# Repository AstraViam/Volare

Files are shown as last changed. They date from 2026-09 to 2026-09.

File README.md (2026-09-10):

# Volare

Full electronic, structural and hydrodynamic design code for **Team Volare**,
ICT Mumbai, competing in the **Monaco Energy Boat Challenge 2026**, Energy Class.

A 5 m, 250 kg catamaran. The design objective throughout is **minimum electrical
energy per nautical mile**, not maximum propeller efficiency, and every model
here serves that one number.

> **New here, or picking this up in a new session? Read [`HANDOFF.md`](HANDOFF.md) first.**
> It carries the current state, what is blocked, and what to do next.

---

## What is in here

Four codebases that share one parameter file and are otherwise independent.

### `powertrain/` — battery pack and drivetrain (MATLAB)

The Molicel P50B 26S21P pack, from cell data through busbar sizing and thermal
design to the mission simulation and Monaco compliance check. Numbered folders
`00_common` through `09_hydro` run in dependency order.

```matlab
% open MATLAB at powertrain/
SMOKE_TEST        % fast check
RUN_EVERYTHING    % full run, a few minutes
TEST_ALL          % regression suite
```

### `cad/` — geometry, structure and optimisation (Python)

`cad/scripts/` is pure numpy and scipy: hull geometry, frame sizing, mass
budget, hydrostatics, aerodynamics and the shape optimiser. Every module
self-tests and exits non-zero on failure.

`cad/blender/` consumes `cad/scripts/` to build and render scenes. It never
reimplements the maths.

```bash
python -m venv .venv && .venv/bin/pip install numpy scipy matplotlib
.venv/bin/python cad/scripts/mass.py
blender -b -P cad/blender/build_scene.py
```

### `propulsor/` — contra-rotating propulsor optimiser (MATLAB)

**Currently incomplete.** Core solver files are missing from the repository;
see `propulsor/README.md`.

### `notes/` and `docs/` — the design record

`notes/00` through `notes/09` are the original design discussion and are
**partly superseded**. Where a note and a script disagree, the script wins:
every number in `cad/scripts/` was re-derived or re-measured from the supplied
STLs, and the scripts check themselves.

`docs/design/` holds the current engineering records. `docs/reference/` holds
the Monaco 2026 rules and the cell datasheet.

---

## Layout

```
notes/              00-09 design notes (partly superseded)
docs/design/        current engineering records
docs/reference/     competition rules, datasheets
docs/decisions/     architecture decision records
powertrain/         MATLAB pack + drivetrain project
cad/scripts/        pure numpy/scipy geometry and physics
cad/blender/        bpy scene builders and renderers
cad/freecad/        FreeCAD STEP export
cad/out/            generated .blend, .json, .csv, figures/
propulsor/          contra-rotating optimiser (incomplete)
source_documents/   supplied cockpit STLs — never modify
tools/              repository utilities
```

The two numbered layouts are not cosmetic. `powertrain/TEST_ALL.m` asserts its
exact folder structure, and `P50B_ProjectRoot.m` derives the project root from
its own position inside `00_common/`. The Python modules resolve data through
`Path(__file__).parents[2]`. **Do not flatten either tree.**

---

## Conventions

**Frame.** X forward, Y port, Z up. Origin at centreline × hull mid-length ×
keel bottom. Millimetres everywhere except Blender scenes, which are metres.
Neither supplied STL uses this frame and the two disagree with each other;
`cad/scripts/volare.py` holds both transforms and self-checks them. Always go
through it.

**Supplied parts are locked.** The hulls and beams must not be modified
(ENERGY_REQ_3). `cad/blender/build_scene.py` enforces this.

**Verify by measuring, not by re-reading parameters.** The scene builders
re-measure the geometry they built and fail on disagreement. That has caught
real bugs that parametric checks could not. Add a measured check whenever you
add geometry.

**Report outcomes faithfully.** If a check fails, say so with the number. When a
computed result contradicts a note, say which note and why, and leave a comment
at the site of the correction.

---

## Status

| Subsystem | State |
|---|---|
| `powertrain/` | Structured and consistent. Blocked on two measured cell data files and the shared parameter file. |
| `cad/scripts/` | 14 of 16 modules pass their self-tests. The other two are blocked on the shared parameter file. |
| `cad/blender/` | Requires Blender; not exercised in CI. |
| `propulsor/` | Incomplete. Core solver files missing. |

Full detail, including every missing file and what it blocks, is in
[`HANDOFF.md`](HANDOFF.md).

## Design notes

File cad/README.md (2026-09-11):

# cad/ — geometry, structure and optimisation

The engineering record for everything geometric. Pure Python maths is separated
from Blender scene building on purpose, and that separation is enforced by
review rather than by tooling, so keep it.

| Folder | Runtime | Rule |
|---|---|---|
| `scripts/` | numpy, scipy | No `bpy`, ever. All physics and geometry maths lives here. Every module self-tests and exits non-zero on failure. |
| `blender/` | Blender's Python | Consumes `scripts/`, never reimplements it. Adds `cad/scripts` to `sys.path` itself. Blender has no scipy, so keep heavy imports lazy. |
| `freecad/` | FreeCAD's Python | STEP export only. |
| `out/` | — | Generated `.blend`, `.json`, `.csv`. `out/figures/` holds rendered PNGs. Tracked, so teammates without Blender still have them. |

## Parameters drive the geometry

Every engineering number comes from `powertrain/params/volare_params.json`.
Change it and the change reaches the CAD without anybody editing code. That is
what lets design work and analysis run in parallel.

```
powertrain/params/volare_params.json      the single source of truth
        |
        |  cad/scripts/params.py           stdlib-only loader, works under
        |                                  CPython, Blender and FreeCAD alike
        v
  cad/scripts/volare.py                    shared constants, now derived
        |                                  (mass cap, pilot mass, beam
        |                                   diameter, clamp limits, air)
        +--> parametric.py, frame.py, mass.py, aero.py, ...
        |
  cad/scripts/powertrain.py                computes the layout
        |
        v
  cad/out/powertrain.json                  the one geometry both builders read
        |
        +--> cad/blender/*        meshes, renders, the .blend
        +--> cad/freecad/*        B-rep solids, the STEP a supplier can open
```

Blender and FreeCAD consume the same JSON, so they cannot disagree about where
anything is. Neither reads a parameter directly, which is deliberate: one place
computes the layout, everything downstream consumes it.

The cost of that is staleness, so the FreeCAD build refuses to run when
`cad/out/powertrain.json` is older than the parameter file, rather than writing
a STEP that looks authoritative and describes the previous design. Override
with `VOLARE_ALLOW_STALE=1` only when you mean it.

**What stays hardcoded, on purpose.** The STL-derived numbers in `volare.py`
are measurements of supplied geometry, re-derived from the files and
self-checked at the bottom of that module. They are not design choices anybody
may vary, so they are not parameters.

**Adding a number.** Put it in the parameter file with a provenance tag, then
read it with `params.get("section.name")`. Never add a literal to a script. A
missing parameter raises rather than falling back to a plausible default,
because a CAD model built on invented dimensions looks authoritative and is
not.

## Path contract

Modules resolve the repository root as `Path(__file__).resolve().parents[2]`.
That means **`cad/scripts/` must stay exactly two levels below the repository
root**. Moving it breaks every data path at once. The same applies to
`cad/blender/`.

From that root the modules expect `cad/out/`, `cad/out/figures/` and
`source_documents/`.

## Running

```bash
.venv/bin/python cad/scripts/mass.py
for f in cad/scripts/*.py; do .venv/bin/python "$f" || echo "FAIL $f"; done

blender -b -P cad/blender/build_scene.py -- --out cad/out/volare_baseline.blend
blender -b cad/out/volare_baseline.blend -P cad/blender/render_views.py
```

`powertrain.py` and `pack_fit.py` currently fail on a missing shared parameter
file. See `HANDOFF.md` section 5.

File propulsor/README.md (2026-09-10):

> **STATUS: INCOMPLETE — `main.m` cannot run yet. Being rebuilt, not restarted.**
>
> 13 of the 32 planned files exist. The solver core that is present —
> `bem_rotor.m`, `crp_interaction.m`, `surface_piercing_model.m` and
> `config.m` — is sound and is being kept. What is missing is the surrounding
> layer, starting with `units.m`, whose absence stops `config()` running at all.
>
> **Read [`DESIGN.md`](DESIGN.md) before touching anything here.** It carries
> the architecture, the file-by-file plan, the `params` schema, the staged
> build order, and the MATLAB-versus-Octave decision.
>
> The document below is the engineering rationale to build against.

---

# MEBC Energy Class — Coaxial Contra-Rotating Propulsor Design Tool

MATLAB design and optimisation framework for the contra-rotating propulsor of a
5 m, 250 kg catamaran at 20 knots. Written for Team Volare, ICT Mumbai.

The objective is **minimum electrical energy per nautical mile**, not maximum
propeller efficiency. Everything from hull resistance to battery current is in
one chain, and every unmeasured input is declared, configurable and swept.

---

## 1. Modelling architecture

```
config.m ──► params  (single source of truth for every engineering number)
                │
   resistance_model ──► hull_interaction ──► required thrust T = R/(1-t)
                │
   propeller_geometry ──► hydrofoil_polar ──► bem_rotor ──┐
                                                          ├─► crp_interaction
   surface_piercing_model / submerged_model ──────────────┘   (coupled, iterative)
                │
   gearbox_model ──► motor_model ──► electrical power ──► Wh/nm
                │
   cavitation_model + structural_model + constraints
                │
   objective_function ──► optimization_driver ──► postprocess / export / plots
```

### 1.1 What is actually solved

**Blade element momentum, per rotor** (`bem_rotor.m`). Standard propeller
convention, `U_a = V_a(1+a)`, `U_t = Ωr(1−a′) + V_t`, Prandtl tip *and* hub
losses, 24 cell-centred radial stations. The coupled `(a, a′)` system is reduced
to **one scalar equation per station in the inflow angle φ** and solved by
Illinois (bracketed false position), which converges unconditionally. A
fixed-point iteration on `(a, a′)` was tried first and is unstable at high
solidity; that is why it is not used.

The radial grid is **cell-centred**, deliberately. A station exactly at `r = R`
puts the Prandtl factor at zero, drives the momentum-derived induction to
infinity, forces the solver onto its clamp, and leaves spurious load on an
element that physically carries none.

**Contra-rotating coupling** (`crp_interaction.m`). The rotors are *not* solved
independently:

| Effect | Model |
|---|---|
| Front → rear axial | `g_dn = 1 + Δx/√(Δx²+R_F²)` ≈ 1.25 at 50 mm — the front's induction is only ~25 % developed at the rear disk |
| Rear → front axial | `g_up = 1 − Δx/√(Δx²+R_R²)` ≈ 0.75 — the rear's induction is felt strongly upstream |
| Slipstream contraction | discrete mass conservation, `r₂² = r₂,prev² + u₁(r₁²−r₁,prev²)/u_dn` |
| Swirl transport | `v_θ2 = 2a′₁Ω₁r₁·(r₁/r₂)` — circulation conserved through contraction |
| Swirl recovery | positive `flow.Vt` on the rear rotor, so recovery falls out of the momentum balance — it is **not** an applied efficiency factor |
| Upstream swirl | zero, correctly: an actuator disk induces no tangential velocity ahead of itself |

The coupling is **positive feedback** — more rear loading raises the axial
velocity at the front disk, which unloads the front, which weakens the swirl
feeding the rear. Near lightly loaded operating points the loop gain exceeds
one, the fixed point is *repelling*, and no under-relaxation factor converges.
The coupling is therefore reduced to a single scalar (the interference
amplitude `u`) and solved by secant with a guaranteed-bracket bisection
fallback. This is documented in the file header because it is not obvious and
it will bite anyone who tries to "simplify" it back to a relaxed iteration.

**Speed is not a free variable.** For every candidate design the solver finds
the rotational speed that delivers exactly the required thrust, using a
two-term `T(n) = A n² + B n` model-based secant. The thrust equality constraint
therefore disappears from the optimiser: every evaluated design satisfies it by
construction, or is reported infeasible with a reason.

**Surface piercing** (`surface_piercing_model.m`) is deliberately two-level:

- *Level 1, cycle-averaged*: immersion duty `duty(r) = 1 − acos(h/r)/π`
  multiplies **both** the blade-element force and the annulus momentum area.
  The duty cancels in the induction relations, so partial immersion does not
  change `a` at a given speed — it cuts the thrust, so the solver raises the
  speed, which *then* raises `a`. That is precisely the reduced-disk-area
  induced-loss penalty, obtained from the momentum balance rather than applied
  as a fudge.
- *Level 2, azimuthal*: instantaneous loads reconstructed over one revolution
  for peak/mean/cyclic torque, which is what the shaft, gearbox and blade root
  have to survive.

Ventilated sections use linearised supercavitating theory, `Cl = k_sc·(π/2)·α`,
roughly **a quarter** of the wetted-section lift at the same incidence, plus
base drag. This is the dominant physical penalty of surface-piercing operation
and the reason SP propellers need high pitch. Cavitation and ventilation are
computed and reported **separately** — they are different phenomena with
different criteria and different consequences.

---

## 2. Findings that came out of the model, not out of the brief

**The motor specification is inconsistent in two ways, not one.** The brief
identified that 42 kW is unreachable at 100 N·m and 2500 rpm (ceiling
26.18 kW). The tool also flags that **25 kW cannot be produced at the quoted
1300 rpm nominal speed either** — at 1300 rpm and 100 N·m the ceiling is
13.6 kW, and 25 kW at 100 N·m needs at least 2387 rpm. Nothing supplied has
been altered; `P_available(n) = min(P_continuous, 2πnQ_max)` is enforced and
both inconsistencies are printed at the top of every report.

**The propulsor is profile-drag dominated, not induced-drag dominated.** At
20 kn with ~780 N of thrust on a 0.5 m disk the thrust loading coefficient is
`C_Th ≈ 0.07`, giving an ideal induced efficiency above 0.98. Almost the entire
loss is blade friction. The design therefore wants *low blade area and low
rotational speed*, and the optimum diameter is well below the 21 in limit —
which is the opposite of the usual "make it as big as it fits" instinct.

**The reference configuration is badly matched.** With equal diameters, equal
speeds and 26.5″/28.5″ pitch, the model puts almost all the load on the rear
rotor (the front's swirl raises the rear's incidence while the rear's upstream
induction unloads the front) and the rear massively over-corrects the swirl.
The baseline-versus-optimised table quantifies this.

**Surface piercing versus submerged at 20 kn is decided by drive-leg drag, not
by the propeller.** The ventilated sections give up a lot of L/D, but the SP
configuration removes most of the submerged leg. Both effects are modelled
explicitly and both are swept in the sensitivity analysis. Do not treat the
verdict as settled without CFD.

**The CFD reference set may be internally inconsistent.** `J = 0.60`,
`n = 4220 rpm` and `V_A = 3.4 m/s` imply a propeller diameter of **80.6 mm**.
`validation.m` reports this and asks for confirmation, because if the CFD model
was not an 81 mm propeller then one of the three numbers is wrong and the
reference set cannot be used. Thrust was not supplied, so `K_T` and `η₀` are
reported as *"Not available — requires CFD/experimental validation"* rather
than invented.

---

## 3. Running it

```matlab
cd mebc_crp
RES = main();                          % full run: both architectures, 4 blade combos
RES = main('quick', true);             % reduced optimiser budget, ~10x faster
RES = main('arch', 'sub');             % fully submerged only ('sp' for surface piercing)
RES = main('plots', false);            % no figures
RES = main('report', 'myrun.txt');     % also write the report to results/myrun.txt
```

Runtime is dominated by the coupled solver: roughly **1–1.5 s per candidate
design in MATLAB** (≈3 s in Octave). A full run is a few hours; `quick` mode is
tens of minutes. Start with `quick` while you are changing assumptions, then do
one full run.

**No toolbox is required.** The particle swarm and the pattern search in
`optimization_driver.m` are implemented in plain MATLAB and run on a base
licence and on GNU Octave. Set `params.optimization.useToolbox = true` to use
`particleswarm`/`fmincon` instead; the code checks at run time and falls back
silently if they are absent. The random stream is seeded from
`params.optimization.seed`, so runs are reproducible.

### Files produced (in `results/` and `figures/`)

| File | Contents |
|---|---|
| `design_report.txt` | The full report: assumptions, motor audit, optimised design, gearbox spec, sanity checks, sensitivity, limitations |
| `front_blade_geometry.csv` | **→ CAD/Ansys.** Per radial station: r/R, r, chord, pitch, pitch angle, camber, thickness, skew, rake, reference-line and LE/TE Cartesian coordinates, plus the local hydrodynamic state |
| `rear_blade_geometry.csv` | Same, rear rotor |
| `design_summary.csv` | One-line-per-quantity summary for spreadsheets |
| `optimisation_results.mat` | Full result structure for further analysis |
| `figures/01..09_*.png` | Resistance, open-water curves, CRP performance, motor envelope, radial loading, optimisation history, SP cyclic loads, blade geometry, blade outline |

**Take into CAD/Ansys:** the two `*_blade_geometry.csv` files. They carry the
blade reference line and LE/TE coordinates at every station, plus a header
block recording D, Z, P/D, EAR, hub diameter, rpm, thrust, torque, axial gap
and shaft angle, so an exported blade is always traceable to the run that made
it. The tool does **not** emit section offsets, because no hydrofoil family has
been specified — once you choose one, generate the offsets from the `t/c` and
`f/c` columns.

---

## 4. Reading the report

Work through it in this order:

1. **ASSUMPTIONS AND UNVERIFIED INPUTS** — everything the answer is conditional
   on. If a number here matters to your decision, measure it before trusting
   the result.
2. **MOTOR SPECIFICATION AUDIT** — the torque-speed-power consistency check.
3. **OPTIMISED DESIGN** — geometry, operating point, splits, efficiency chain.
   Note that `η₀` printed per rotor is the *isolated* rotor efficiency and is
   **not** the CRP system efficiency; use `η_CRP`.
4. **MOVEMENT AWAY FROM THE REFERENCE PITCH** — if a variable sits on its search
   bound, the bound is setting the answer, not the physics. Widen it and rerun.
5. **BLADE-COUNT COMPARISON** and the Pareto set.
6. **REQUIRED GEARBOX SPECIFICATION** — hand this to whoever designs the box.
7. **ENGINEERING SANITY CHECKS** — 14 automatic checks, each with its numbers.
8. **SENSITIVITY ANALYSIS** — ranked by influence on Wh/nm. This tells you where
   to spend measurement effort.
9. **MODEL LIMITATIONS AND REQUIRED VALIDATION** — read this before quoting any
   number to anyone.

---

## 5. Replacing assumptions with data

Every one of these is a `config.m` edit; none requires touching the solver.

| When you obtain | Set |
|---|---|
| Motor efficiency map | `params.motor.etaMap = @(rpm,Q) ...` |
| Measured wake / thrust deduction | `params.hull.w`, `params.hull.t`, `params.hull.eta_R` |
| CFD wake field | `params.hull.wakeField = [rR(:), w(:)]`, `useWakeField = true` |
| 300 kg resistance curve | `params.resistance.speed_kn_300`, `R_total_N_300` |
| Gearbox data | `params.gearbox.eta`, `ratio_min/max`, `serviceFactor` |
| Stainless grade | `params.material.*` (density, E, ν, yield, ultimate, fatigue) |
| Hydrofoil polars | `params.polar.external` (fields `alpha, Re, Cl, Cd`), `useExternal = true` |
| Shaft immersion | `params.surfacePiercing.hShaft_over_R` |
| SP CFD | `params.surfacePiercing.k_sc`, `Cd_base`, `entryAngle_deg`, `entryEfficiency` |
| Propeller CFD for validation | `params.validation.cfd.*` and `params.validation.geometry` |

---

## 6. Honest statement of what this is

This is a **transparent, parameterised preliminary design and trade-study
framework** whose every assumption is declared and replaceable, suitable for
iterative refinement through Ansys CFD and physical testing.

It is **not** a validated performance prediction. Blade element momentum theory
with empirical corrections is not equivalent to CFD. The surface-piercing
corrections in particular — water entry and exit, spray sheet, added mass,
cavity closure, ventilated section polars — are the weakest link, and the
Level-2 cyclic loads reconstruct immersion *kinematics* only, so peak loads are
**underestimated**. Blade natural frequencies are not computed at all, and they
matter for a propeller that is impulsively loaded once per revolution.

Nothing in the output is fabricated. Where data is missing, the tool says
*"Not available — requires CFD/experimental validation"* and carries on.

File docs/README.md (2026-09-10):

# docs/

| Folder | Contents |
|---|---|
| `design/` | Current engineering records. These supersede `notes/` where they disagree. |
| `reference/` | Monaco 2026 rules, notice of challenge, cell datasheet. Read-only source material. |
| `decisions/` | Architecture decision records: why the repository is shaped the way it is. |

The original design discussion lives in `notes/` at the repository root, not
here. It is partly superseded; see `notes/README.md`.

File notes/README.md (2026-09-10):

# notes/ — the original design discussion

**Partly superseded. Not ground truth.**

These ten notes are the design discussion as it happened. Where a note and a
script disagree, **the script wins**: every number in `cad/scripts/` was
re-derived or re-measured from the supplied STLs, and the scripts self-check.

Known correction: note 06 conflates cockpit mass with supplied mass and
overstates the overage against the 250 kg cap by roughly 80 kg. Use
`cad/scripts/mass.py`.

| Note | Subject |
|---|---|
| `00-master-brief.md` | Scope, objective, frozen constraints |
| `01-aerodynamic-redesign.md` | Aero redesign |
| `02-support-frame-design.md` | Support frame |
| `03-composite-structure.md` | Composite layup |
| `04-fluent-cfd-setup.md` | Fluent CFD setup |
| `05-manufacturable-optimisation-workflow.md` | Optimisation workflow |
| `06-powertrain-battery-and-solar.md` | Powertrain, battery, solar |
| `07-why-beam-position-beats-beam-size.md` | Beam position argument |
| `08-frame-solution-at-fixed-span.md` | Frame at fixed span |
| `09-rules-audit-and-open-questions.md` | Rules audit, open questions |

Filenames were kebab-cased from their original spaced form so they no longer
need quoting in shell commands and scripts. All references were updated.

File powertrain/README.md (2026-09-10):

# powertrain/ — Molicel P50B 26S21P pack and drivetrain

Self-contained MATLAB project. Open MATLAB **at this folder**, not at the
repository root.

```matlab
SMOKE_TEST        % fast check during development
RUN_EVERYTHING    % every entry point in dependency order, a few minutes
TEST_ALL          % regression suite
P50B_BUILD        % builds the Simscape battery library into output/
```

`RUN_EVERYTHING.m` calls `addpath(genpath(...))` on this folder, so the numbered
subfolders resolve automatically.

## Layout — do not flatten

`TEST_ALL.m` contains a 23-entry manifest asserting this exact structure, and
`P50B_ProjectRoot.m` derives the project root from its own position inside
`00_common/`. Both break if files are moved to the root.

| Folder | Contents |
|---|---|
| `00_common/` | Parameter plumbing, provenance, project root, architecture audit |
| `01_cell/` | Cell definition, OCV, DCIR |
| `02_pack/` | 21P → 13S21P → 26S21P assembly |
| `03_mechanical/` | Geometry, group layout, cell coordinates, busbars, plots |
| `04_data/` | Measured input tables. `hydrodynamics/` holds the hydro design report |
| `05_tests/` | Electrical and busbar tests plus their fixtures |
| `06_drivetrain/` | Motor, inverter, harness, auxiliary loads, gearbox, propeller |
| `07_simulation/` | Mission profile, mission run, thermal design |
| `08_compliance/` | Monaco compliance, mass budget, verification |
| `09_hydro/` | Hull model, boat dynamics, boat performance |
| `models/` | Simulink and Simscape models (`.slx`) |
| `output/` | Generated artefacts. Tracked so teammates without MATLAB have them |
| `params/` | Shared parameter file — **currently missing, see HANDOFF.md** |

## Sharing numbers with the Python side

`params/volare_params.json` is the single source of truth shared with
`cad/scripts/`. Never duplicate a constant across the two languages. If a number
matters to both, it belongs in that file.

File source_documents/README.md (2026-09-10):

# source_documents/ — supplied geometry

Cockpit STLs supplied by the organisers. **Never modify these files, and never
modify the hulls or beams they describe** (ENERGY_REQ_3). They are locked in
`cad/blender/build_scene.py` via `lock()`.

`cad/scripts/geom.py` reads them from here by name. Neither STL uses the
project's canonical frame and the two do not agree with each other;
`cad/scripts/volare.py` holds both transforms and self-checks them. Always go
through it.

Competition rules and datasheets live in `docs/reference/`, not here.

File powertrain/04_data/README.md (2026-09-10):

# powertrain/04_data/

Measured input tables. These are inputs a human or an instrument produced, not
solver output; solver output goes to `powertrain/output/`.

## Present

`P50B_BusbarLinks.csv`, `P50B_BusbarOperatingPoints.csv`,
`P50B_CellCoordinates.csv`, `P50B_GroupCoordinates.csv`, `P50B_ThermalTable.csv`,
`P50B_ParameterProvenance.csv`, `P50B_MonacoCompliance.csv`,
`P50B_VerificationChecks.csv`, and `hydrodynamics/design_report.txt`.

## Missing

| File | Read by | How to produce it |
|---|---|---|
| `P50B_OCV_SOC.csv` | `01_cell/P50B_OCV.m` | Measured open-circuit voltage against state of charge, from an HPPC pulse sequence |
| `P50B_DCIR_SOC_T.csv` | `01_cell/P50B_DCIR.m` | Measured DC internal resistance against SOC and temperature, from the same HPPC run |

Both are declared in `SMOKE_TEST.m`'s `dataFiles` manifest. Until they exist,
the cell model cannot be validated against measurement.

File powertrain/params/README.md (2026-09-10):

# powertrain/params/

## volare_params.json — MISSING

This folder should hold `volare_params.json`, the single parameter file shared
between the MATLAB and Python sides of the project. **It was not part of the
upload and is not in the repository.**

It is read by:

- `powertrain/00_common/P50B_LoadParams.m`
- `cad/scripts/powertrain.py`
- `cad/scripts/layout.py`

and its absence blocks `cad/scripts/powertrain.py`, `cad/scripts/pack_fit.py`
and the MATLAB parameter checks in `SMOKE_TEST.m`.

`powertrain.py` refuses to substitute defaults, and that is the correct
behaviour: a CAD model built on invented dimensions looks authoritative and is
not. Do not add a placeholder file to make the error go away.

Also expected here, and also missing:

- `cells/p50b_derived.json`, generated by `tools/export_cell_tables.py`
  (which is itself missing).

Restoring `volare_params.json` is the single highest-value action available;
see `HANDOFF.md` section 5.

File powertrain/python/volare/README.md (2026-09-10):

# volare — coupled pack, boat and race model

Coupled electro-thermal pack model, boat dynamics and race simulation for the
Monaco Energy Class P50B 26S21P.

```bash
cd powertrain/python/volare
pip install numpy scipy matplotlib     # the only dependencies
python run.py                          # build everything
python verify.py                       # all five verification layers
```

See `../../QUICKSTART.md` for the full command table, `../../DATA_NEEDED.md`
for which numbers are still estimates, and `../../SABOTAGE.md` for how the
verification was itself validated.

## Two import styles, both supported

Modules import each other flatly (`import pack_thermal as pt`) and run directly
from inside this folder. `__init__.py` also puts this directory on `sys.path`
at import time, so `from volare.params import load` works from `powertrain/`.
Do not rewrite the flat imports.

## Paths

`params.py` resolves `project_root()` as two levels above this folder, which is
`powertrain/`. From there it reads `params/volare_params.json`, the single
source of truth that MATLAB and `cad/scripts/` also read. **This folder must
stay at `powertrain/python/volare/`.**

`figures/` is generated and git-ignored; `verify.py` rebuilds it in about eight
seconds. `celldata/p50b.json` is generated by `build_p50b_dataset.py` but is
tracked, because it is 14 KB and the invariants suite needs it on a fresh clone.

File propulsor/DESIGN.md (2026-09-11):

# Propulsor design framework — architecture and build plan

Coaxial contra-rotating propulsor for the Team Volare MEBC Energy Class
catamaran. Design point 20 knots, 250 kg, seawater.

Status: **planning document.** No new code written yet. This is the structure
we build against.

---

## 1. Verdict: salvage, do not delete

You asked whether to delete `propulsor/` and start fresh. **Do not.** The
existing 2,491 lines already implement the harder half of your specification,
and they implement it well.

Evidence, from reading the code rather than the README:

- **`bem_rotor.m` is not toy code.** It reduces the coupled `(a, a')` system to
  one scalar equation per station in the inflow angle and solves it with
  Illinois bracketing, which converges unconditionally, having explicitly
  rejected fixed-point iteration as unstable at high solidity. It uses a
  cell-centred radial grid so no station sits at `r = R` where the Prandtl
  factor vanishes and the induction diverges. It shows that the immersion duty
  factor cancels in the induction terms but not in the loads, which is the
  correct physical statement of the surface-piercing disk-area penalty. That is
  the reasoning your spec section 19 asks for, already done.
- **`optimization_driver.m` already contains `pso_local` and `pattern_search`.**
  Your spec section 32 asks for "a fallback version that does not require
  proprietary optimization toolboxes." It exists.
- **`objective_function.m` already contains** `manufacturability_penalty` and
  `robustness_penalty` (spec section 30).
- **`surface_piercing_model.m` already contains** `immersion`, `ventilation`
  and `cyclic` (spec sections 14 and 36).
- **`crp_interaction.m` already contains** `interp_slipstream` for contraction
  (spec section 15).
- **`config.m` already carries an assumption ledger** via `add_assumption`
  (spec section 53).

What is missing is the *surrounding* layer: 19 files, mostly the simpler ones.
Deleting would throw away the BEM solver, the CRP coupling and the
surface-piercing kinematics — precisely the parts that are hard to get right —
and rebuild them from scratch at the same design.

**Plan: keep the four solver files and `config.m`, write the missing 19 around
them, and refactor only where the new spec genuinely conflicts.**

---

## 2. The MATLAB environment — the real answer

This is the question with the largest effect on how fast this goes.

### The problem

Claude Code sessions have no MATLAB and never will. Nothing in `powertrain/`
or `propulsor/` has ever been executed in a session. A 22-file BEM and
optimiser framework that has never been run is, with near certainty, broken.
Writing more MATLAB that nobody can execute until you open it on your laptop
is the slowest possible loop.

### The fix: GNU Octave as the development and CI runtime

Octave 8.4 is now installed in this environment, and **every existing
`propulsor/*.m` file parses cleanly in it.** The code contains zero
MATLAB-only constructs: no `arguments` blocks, no `string()`, no `classdef`,
no `dictionary()`. It was written portably, whether or not that was deliberate.

That means the numerical core can be developed test-first, run on every push
in CI, and only taken to real MATLAB for the things Octave genuinely cannot do.

### What Octave cannot do, and what to do about it

| Need | Octave | Plan |
|---|---|---|
| `particleswarm`, `ga`, `patternsearch` | Absent (Global Optimization Toolbox) | Use the existing `pso_local` and `pattern_search`. Call the toolbox only when `exist('particleswarm','file')` says it is there. |
| `fmincon` | Absent | `sqp` in Octave's `optim` package, or a penalty formulation on top of the existing local search. Keep behind the same capability check. |
| `optimoptions` | Absent | Wrap in a thin `opt_options()` shim that returns a plain struct under Octave. |
| Simulink / Simscape | Absent | Not needed here. This is `powertrain/`'s problem, and it stays on your machine. |
| `pchip` (spec section 3) | **Present** | Use directly. |

Two of the existing files use name=value call syntax, which Octave 8 accepts
but older versions do not. Prefer `'name', value` pairs for portability.

### Recommended split

- **Here and in CI:** Octave. Every solver, every unit test, every sanity check
  from spec section 49, the full toolbox-free optimisation path.
- **On your machine:** MATLAB. Toolbox optimisers for the final production runs,
  plotting for report figures, and anything touching Simulink.
- **MATLAB in CI, now worth doing.** You have confirmed MATLAB access for
  anyone with an institute email, which means a Campus-Wide Licence. Those
  normally permit CI through `matlab-actions/setup-matlab` with a batch
  licensing token. The steps:

  1. Ask IT for a MATLAB batch licensing token for CI, or check whether the
     Campus-Wide Licence already covers `matlab-actions`.
  2. Store it as a repository secret named `MATLAB_BATCH_TOKEN`.
  3. Add a job mirroring the Octave one, running `tests/ci.m` under MATLAB.

  Keep **both** jobs. Octave is the fast gate that runs on every push in
  seconds; MATLAB is the fidelity gate that proves the code behaves
  identically on the runtime the team actually uses, and is the only way to
  exercise the toolbox optimiser path. If the two ever disagree, that
  disagreement is itself the bug worth finding.

### MATLAB Online

Also available to anyone with the institute email, at matlab.mathworks.com.
Useful for a teammate without a local install to open a `.slx` model or run a
one-off script. Not useful for development here, because it has no access to
this repository's working tree.

### The rule this imposes on new code

**Write to the MATLAB/Octave intersection.** Concretely: no `arguments`
blocks, no `string` type (use char arrays and cellstr), no `classdef` unless
genuinely needed, no `dictionary`, no `containers.Map` in hot paths, and every
toolbox call guarded. A CI job will enforce this by running the suite in
Octave, so a violation fails the build rather than surfacing three weeks later.

---

## 3. Architecture

Data flows one way. Every stage is a pure function of `params` plus its
upstream inputs, so any stage can be tested alone.

```
config.m ──► params  (every engineering number originates here)
    │
    ├─► load_inputs.m        external data replaces assumptions in-place
    │
    ▼
resistance_model.m   pchip over the supplied 5-point curve  ──► R_T(V)
    │
    ▼
hull_interaction.m   w, t, eta_R  ──► T_required = R_T/(1-t),  V_A = V(1-w)
    │
    ▼
propeller_geometry.m  spline-parameterised blade  ──► g_front, g_rear
    │                 (chord, pitch, camber, thickness, skew, rake vs r/R)
    ▼
hydrofoil_polar.m     Cl(alpha,Re), Cd(alpha,Re)  ──► section data
    │
    ▼
┌───────────────────── crp_interaction.m (coupled, iterative) ─────────────┐
│  bem_rotor(front) ──► a, a', slipstream contraction, swirl               │
│         │                                                                │
│         ▼  axial acceleration + swirl transported to the rear disk        │
│  bem_rotor(rear)  ──► recovers swirl as useful thrust                    │
│         │                                                                │
│         └──► iterate to convergence on the coupled induction field       │
└──────────────────────────────────────────────────────────────────────────┘
    │                                    │
    │  surface_piercing_model.m          │  submerged_model.m
    │  immersion, ventilation, cyclic    │  baseline comparison
    ▼                                    ▼
cavitation_model.m + structural_model.m   constraint feasibility
    │
    ▼
gearbox_model.m   n_motor, ratios, torque split  ──► required transmission
    │
    ▼
motor_model.m     P_available(n) = min(P_cont, 2*pi*n*Q_max),  eta_motor
    │
    ▼
objective_function.m   ──►  Wh per nautical mile   ◄── THE metric
    │
    ▼
optimization_driver.m  4 stages: coarse global ► refine ► local ► robustness
    │
    ▼
postprocess.m ─► plot_performance.m, plot_geometry.m, export_geometry.m,
                 sensitivity_analysis.m, validation.m
```

### The one architectural rule

**The rear rotor never sees boat speed.** Its inflow is the front rotor's
slipstream: accelerated axially, contracted radially, and carrying swirl that
the rear rotor is there to recover. Any code path that passes `V_A` straight to
the rear rotor is a bug, not a simplification.

---

## 4. File plan

22 files. Status is measured, not guessed.

### Keep as-is, or refactor lightly

| File | Lines | Notes |
|---|---:|---|
| `bem_rotor.m` | 206 | The core. Illinois solver, cell-centred grid, duty factor. Spec section 19 wants `bem_front_rotor.m` and `bem_rear_rotor.m` as separate files; **resist that.** One rotor solver called twice is correct; two copies drift apart. |
| `crp_interaction.m` | 337 | Coupled front/rear. Verify the positive-feedback handling the README describes. |
| `surface_piercing_model.m` | 211 | Immersion, ventilation, cyclic loading. |
| `config.m` | 343 | Extend to the full schema in section 5 below. |
| `objective_function.m` | 110 | Confirm the objective is Wh/nm, not efficiency. |
| `constraints.m` | 97 | Extend to the full section 33 list. |
| `optimization_driver.m` | 244 | Add the toolbox capability check. |
| `validation.m` | 140 | Wire to the CFD reference point. |
| `load_inputs.m` | 163 | External data override path. |
| `main.m` | 301 | Orchestration; update once the missing pieces land. |

### To write

| File | Purpose | Difficulty |
|---|---|---|
| `units.m` | Unit conversion table. **Blocks `config()` right now.** Write first. | Trivial |
| `resistance_model.m` | `pchip` over the 5 supplied points. Must tag results interpolated / extrapolated / supplied. | Easy |
| `hull_interaction.m` | `w`, `t`, `eta_H`, `eta_R`. All configurable, all registered as assumptions. | Easy |
| `motor_model.m` | The envelope, including the 42 kW inconsistency report. | Easy |
| `gearbox_model.m` | Ratios, torque split, required capacity. Pure algebra from the optimum. | Easy |
| `print_assumptions.m` | Section 53's mandatory output block. | Easy |
| `submerged_model.m` | Fully submerged baseline for comparison. | Moderate |
| `cavitation_model.m` | Cavitation number, min pressure coefficient. **Must keep cavitation and ventilation separate.** | Moderate |
| `structural_model.m` | Centrifugal plus bending, safety factor. Label as screening, not FEA. | Moderate |
| `propeller_geometry.m` | Spline-parameterised blade with smoothness constraints. | **Hard** |
| `hydrofoil_polar.m` | `Cl(alpha,Re)`, `Cd(alpha,Re)` with an external-data interface. | **Hard** |
| `sensitivity_analysis.m` | The section 45 sweep. | Moderate |
| `postprocess.m` | Assemble the report. | Easy |
| `plot_performance.m` | Section 41 plots. | Easy |
| `plot_geometry.m` | Blade geometry plots. | Easy |
| `export_geometry.m` | `front_blade_geometry.csv`, `rear_blade_geometry.csv`. | Easy |
| `export_results.m` | Machine-readable run record. | Easy |

### Deliberate deviations from your file list

Your spec section 38 lists `bem_front_rotor.m` and `bem_rear_rotor.m`. **One
`bem_rotor.m` called twice is better.** The rotors differ only in inflow and
rotation sense, both already arguments. Two files would duplicate the solver
and let the copies diverge silently, which is exactly how a rear-rotor bug
survives review.

Everything else in your list is adopted as written.

---

## 5. The `params` schema

One struct, built in `config.m`, threaded everywhere. No number appears
anywhere else. Every unsupplied value registers through `add_assumption()`.

```
params.meta            title, version, created, git commit
params.assumptions     ledger: {field, value, source, effect_if_wrong}
params.units           conversion constants (from units.m)

params.vessel          type, L_hull_m 5.0, spacing_m 2.5, disp_kg 250,
                       disp_worst_kg 300, LCG_m 1.8, V_design_kn 20
params.resistance      V_kn [0 5 10 15 20], R_N [0 89 212 381 624],
                       method 'pchip', source 'supplied', curve_300kg []
params.water           rho, nu, p_vapour, T_C, salinity
params.hull            w, t, eta_R          <- ALL ASSUMPTIONS, flagged
params.motor           P_nom 25e3, P_max_spec 42e3, Q_max 100,
                       n_nom_rpm 1300, n_max_rpm 2500, eta 0.95,
                       V_system 96, eta_map []      <- eta_map replaces eta later
params.propeller.front D_m, Z, P_m, hub_m, chord/camber/thickness splines
params.propeller.rear  same
params.propeller.common D_max_m 0.5334, gap_m 0.05, L_shaft_m 0.5,
                       beta_shaft_deg [-5 5], n_stations 30
params.surfacePiercing shaft_depth, immersion_fraction, waterline,
                       ventilation_model, vent_loss_coeff   <- ALL ASSUMPTIONS
params.gearbox         eta (assumption), ratio_front, ratio_rear, counter_rot
params.material        rho, E, nu, sigma_y, sigma_u, sigma_fatigue, sigma_allow
params.optimization    algorithm, bounds, seed, stage budgets, weights
params.competition     E_stored_kWh 10
params.validation      cfd_ref: J 0.6, n 4220 rpm, Va 3.4, Q 1.06, P 460
params.numerics        tol, max_iter, relaxation, nan_policy
```

---

## 6. Build order

Each stage ends with a runnable check. Nothing proceeds on an unverified stage.

| Stage | Deliverable | Gate |
|---:|---|---|
| 0 | `units.m`, then `config()` runs | **DONE.** 11 checks green |
| 1 | `resistance_model.m` | **DONE.** 16 checks green, including a discriminator that fails if pchip is swapped for linear |
| 2 | `motor_model.m` | **DONE.** 18 checks green, including the 25 kW cap held across 5001 speeds |
| 3 | `hydrofoil_polar.m`, `propeller_geometry.m` | **DONE.** 32 + 29 checks green |
| 4 | `bem_rotor.m` on a single submerged rotor | **DONE.** 17 checks green, including that efficiency never beats the actuator-disc ideal |
| 5 | `crp_interaction.m` coupled | Rear-rotor inflow strictly exceeds `V_A`; swirl recovery positive |
| 6 | `surface_piercing_model.m` | Immersion in [0,1]; cyclic torque amplitude reported |
| 7 | `gearbox_model.m` | Ratios reproduce the rotor speeds from the motor speed |
| 8 | `cavitation_model.m`, `structural_model.m` | Flags fire on a deliberately bad design |
| 9 | `objective_function.m`, `constraints.m` | Baseline evaluates to a finite Wh/nm |
| 10 | `optimization_driver.m` | Beats the baseline; converges; reproducible under a fixed seed |
| 11 | `sensitivity_analysis.m` | Ranks the section 45 parameters |
| 12 | `export_geometry.m`, `validation.m` | CSVs reconstruct the blade; CFD point compared |

**Stage 4 is the one to be honest about.** If the single-rotor BEM does not
produce sane `K_T`/`K_Q` against any published open-water data, nothing
downstream means anything, and the optimiser will happily converge on a number
that is confidently wrong.

---

## 7. The motor inconsistency, resolved numerically

Your section 1 analysis is correct. Computed here:

| Quantity | Value |
|---|---:|
| Power at 2500 rpm and 100 N·m | 26.18 kW |
| Speed for 25 kW at 100 N·m | 2387.3 rpm |
| Torque needed for 42 kW at 2500 rpm | 160.4 N·m (60% over the 100 N·m limit) |
| Speed needed for 42 kW at 100 N·m | 4010.7 rpm (60% over the 2500 rpm limit) |

**42 kW is unreachable inside both hard limits.** It is not a marginal
overshoot; it needs 60% more torque or 60% more speed. `motor_model.m` will
implement `P_available(n) = min(P_cont, 2*pi*n*Q_max)`, keep the 42 kW figure
as a reported specification, and print the contradiction rather than
silently picking one number. Nothing gets altered on your behalf.

Most likely explanation, to check with the supplier: 42 kW is a short-duration
peak measured at a higher speed or a higher voltage than the 96 V bus, or the
100 N·m figure is continuous rather than absolute. **Ask them which.**

### A useful early result

At the design point, with illustrative efficiencies (`eta_0` 0.65,
`eta_gear` 0.95, `eta_motor` 0.95, `eta_ctrl` 0.97):

| Quantity | Value |
|---|---:|
| Effective hull power | 6.42 kW |
| Shaft power | 9.88 kW |
| Electrical power | 11.28 kW, 45% of continuous rating |
| Current at 96 V | 117.5 A |
| Energy per nautical mile | 564 Wh/nm |
| Range on 10 kWh | 17.7 nm, about 53 min at 20 kn |

**The motor is not the binding constraint at 20 knots — the propeller is.**
That reframes the optimisation: there is headroom to trade motor operating
point for propeller efficiency, which is exactly what your section 51 argues
for. Every number above is illustrative until `eta_0` comes from the real BEM.

---

## 8. What we cannot know without CFD or testing

Stated now so no result later overclaims.

| Unknown | Current status | Needed |
|---|---|---|
| Wake fraction `w`, thrust deduction `t` | No measurement. Configurable assumptions. | CFD wake field or self-propulsion test |
| Surface-piercing ventilation | Analytical/empirical only | Free-surface CFD, then tank testing |
| Hydrofoil polars | Provisional model | XFOIL at section Re, or published propeller-section data |
| 300 kg resistance curve | **Does not exist.** Will be reported as unavailable, never extrapolated. | Towing tank or CFD at 300 kg |
| Blade stress | Analytical screening only | FEA |
| Motor efficiency map | Constant 0.95 | Dyno map from the supplier |
| Gearbox efficiency | Configurable assumption | Depends on an architecture not yet chosen |

The framework's job is to be *correct and honest*, not to be accurate before
the data exists. Every one of these slots into `config.m` later without the
solver being touched.

---

## 9. The 25 kW cap — a rule, not a preference

**ENERGY_REQ_188 v1.1, Technical Rules 2027.1:** "The sum of instantaneous
power consumption of all motors shall not exceed 25 kW." Note: "No power
exceeding 25 kW will be allowed, even during a peak."

The 2027 rules tightened this. The 2026 wording capped *nominal* power, which
left room to argue a brief peak was permissible. The 2027 wording caps
*instantaneous* power, summed over all motors, and rules out peaks explicitly.

So `P <= P_cap_W` is a hard feasibility constraint at every operating point,
never a soft penalty. A design that breaches it is not a worse design, it is
an illegal one.

`params.motor.P_cap_W = 25e3` is the enforced ceiling. The supplied 42 kW
datasheet peak stays recorded in `params.motor.P_max_spec_W` with
`usePeakSpec = false`, so the supplied specification is never silently
altered and the contradiction stays visible for the supplier conversation.

The resulting envelope:

| Region | Speed | Limit |
|---|---|---|
| Torque limited | up to 2387.3 rpm | 100 N·m, power rising with speed |
| Power limited | 2387.3 to 2500 rpm | 25 kW, torque falling as `P_cap/omega` |

**At 2500 rpm only 95.5 N·m is available, not 100.** That constraint is live in
`motor_model.m` and gated by `tests/test_stage2_motor.m`, which sweeps 5001
speeds and fails if any point exceeds the cap.

---

## 9b. New 2027 constraints on this subsystem

| Requirement | Constraint | Where it lands |
|---|---|---|
| ENERGY_REQ_194 v1.0 **(new)** | Motor seat must withstand **200% of maximum motor torque**, so **200 N·m** | `structural_model.m` when written, and the frame design |
| ENERGY_REQ_186 v1.1 **(revised)** | **Hydrofoils are not permitted** | Does *not* affect `hydrofoil_polar.m`, which concerns propeller blade sections, not lifting foils. The name collision is unfortunate |
| ENERGY_REQ_195 v1.0 **(new)** | Waterproof 220 × 111 × 80 mm per traction chain for the Organiser's power sensor | Cockpit layout, not this subsystem |

Full change record: `docs/reference/RULES_CHANGES_2026_to_2027.md`.

---

## 9c. First real result from the running model

With the solver working end to end, the first engineering finding is about
pitch. At the 20 knot design point the required thrust is

    T = R_T / (1 - t) = 624 / 0.90 = 693 N

on a 0.5 m disc at 9.77 m/s advance, which is a thrust loading coefficient of
only **C_T = 0.072**. That is very lightly loaded, and the actuator-disc ideal
efficiency at that loading is **0.983**.

Matching the required thrust at a range of pitches gives:

| P/D | n, rev/s | J | eta_o |
|---:|---:|---:|---:|
| 1.0 | 18.7 | 1.05 | 0.503 |
| 1.4 | 15.0 | 1.30 | 0.617 |
| 1.8 | 11.4 | 1.72 | 0.712 |
| 2.2 | 9.1 | 2.14 | 0.752 |

**Efficiency rises monotonically with pitch across the whole searchable range,
and has not turned over by P/D = 2.2.** The supplied reference pitch of 26.5
inches is P/D = 1.35 on a 0.5 m propeller, which sits near the bottom of that
table at about 0.63.

Two consequences:

1. **The configured pitch search bounds are probably too narrow.**
   `params.propeller.front.P07_min_m` and `_max_m` span 22 to 30 inches, which
   is P/D 1.12 to 1.52 at this diameter. The optimum appears to lie well
   outside. Widen them before the first optimisation run, or the optimiser
   will simply pin against the upper bound and report it as converged.
2. **The boat is propeller-limited, not motor-limited, at 20 knots.** The
   earlier chain estimate already showed the motor at 45 percent of its
   ceiling. This says where the recoverable loss actually is.

Both statements come from the provisional polar. They will move when real
section data arrives, but the direction is robust: at C_T = 0.072 a lightly
loaded, slow-turning, high-pitch rotor is the right answer.

---

## 10. Immediate next steps

1. **Stage 3: `hydrofoil_polar.m` and `propeller_geometry.m`.** These are the
   two hard ones, and everything downstream depends on their quality.
2. Ask the motor supplier about the 42 kW figure. The cap makes it moot for
   design, but the answer tells you whether the 100 N·m is truly absolute.
3. Set up the MATLAB CI job, per section 2, now that the licence is confirmed.
4. Stage 4 is the honesty checkpoint: if the single-rotor BEM does not produce
   sane `K_T`/`K_Q` against published open-water data, nothing downstream
   means anything.

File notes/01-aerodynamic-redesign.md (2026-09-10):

---
tags: [volare, aero, cfd, geometry]
---

# 01 — Aerodynamic Redesign

Parent: [[00 - Master Brief]]

## 1. Flow regime

$$V = 15.28\ \text{m/s},\quad q_\infty = \tfrac12\rho V^2 = 143.0\ \text{Pa},\quad Re_{pod} = \frac{VL}{\nu} = 2.59\times10^6$$

Fully turbulent over the pod. Hand-laid gelcoat has Ra ≈ 5–20 µm → equivalent sand-grain roughness k_s ≈ 50–100 µm, giving k_s⁺ = k_s·u_τ/ν ≈ 2–4. That is at the edge of hydraulically smooth, so **model the surface as smooth but run one roughness sensitivity case** (see [[04 - Fluent CFD Setup]] §5).

Hull Froude number Fn = V/√(gL) = **2.18**, volumetric Fn_∇ = 6.65 — fully planing. The hulls will be running on a small aft wetted patch at top speed, which is *why* the aero terms matter so much relative to hydrodynamic drag here.

## 2. Why "reduce eddy viscosity" is not an objective

Eddy viscosity ν_t is the closure variable in the Boussinesq hypothesis:

$$-\overline{u_i'u_j'} = \nu_t\left(\frac{\partial U_i}{\partial x_j}+\frac{\partial U_j}{\partial x_i}\right)-\tfrac23 k\delta_{ij}$$

It is a property of your *turbulence model*, not of the boat. A body with high ν_t in its shear layer is not necessarily draggier — an attached turbulent boundary layer has high ν_t and *low* drag; a separated wake has high ν_t and high drag. Minimising ν_t as an objective would push you toward laminar separation, which is worse.

**Use these as the actual objectives:**

| Objective | Metric | Where to read it |
|---|---|---|
| Minimise pressure drag | C_D·A per component | Fluent force reports, split by wall zone |
| Suppress separation | zero reversed-flow regions | surface skin-friction lines, τ_w < 0 patches |
| Minimise wake losses | total pressure deficit ∫(p₀∞ − p₀)dA | wake plane 1 m aft |
| Avoid vortex shedding on struts | Strouhal peak absent | transient probe, or steady residual oscillation |
| Zero net lift | C_L ≈ 0 ± 0.02 | force report, Z direction |

ν_t is a *diagnostic* — plot it to check your prism layer is resolving the boundary layer (ν_t/ν should peak at 100–500 in the log layer and fall to ~1 at the wall).

## 3. Lift derivation — why to design for zero lift

Lifting-line for a very low aspect ratio body:

$$AR = \frac{b^2}{S} = \frac{0.700^2}{1.518} = 0.323$$

$$C_{Di} = \frac{C_L^2}{\pi\, AR\, e},\qquad e\approx 0.60\ \text{(bluff planform)}$$

At C_L = 0.30: C_Di = 0.09/(π·0.323·0.60) = 0.148, so induced drag is **half the lift** (L/D = 2.03). Lift is 65.1 N; induced drag is 32.1 N.

The lift buys you displacement reduction. For a planing hull, resistance scales roughly R ≈ Δ·(R/W) with R/W ≈ 0.10–0.12 at Fn_∇ ≈ 6.6, so:

$$\Delta R \approx 0.12 \times 65.1\,\text{N} \times 0.6 \approx 4.7\ \text{N}$$

**Net penalty ≈ 27 N.** Structural mass reduction dominates by an order of magnitude: 10 kg removed is 98 N of displacement at *every* speed, with zero drag penalty and no trim moment. That is the lever, and it is why [[03 - Composite Structure]] and [[05 - Manufacturable Optimisation Workflow]] are the high-value notes, not this one.

**Design rule: target C_L = 0 ± 0.02 at 0° and ±3° pitch.** Achieve it with a symmetric-in-Z aft body and a slight negative camber over the coaming to cancel the nose-up moment from the forward deck.

## 4. Pod contour changes (ranked)

### 4.1 Windscreen and pilot fairing — 10.7 N recovered
The exposed pilot is the second largest item in the budget. Add:
- Wraparound windscreen at the forward coaming, **35–40° rake**, top edge at pilot eye level minus 30 mm (pilot looks over it — no optical distortion, no wiper problem)
- Screen top edge radius ≥ 8 mm, side edges swept back 25° so the shed vortex passes outboard of the shoulders
- Shoulder fairings blending the coaming into the headrest peak — this closes the open cavity

Target C_D on pilot frontal: 0.90 → 0.40.

### 4.2 Aft-body recontour — separation control
Current closure angle **15.6°** (deck drops 336 mm over 1200 mm behind the peak). For an attached turbulent boundary layer at this Re, hold the local surface slope **≤ 12°** and the equivalent conical half-angle **≤ 10°**.

Practical fix without lengthening the pod: move the peak aft by ~150 mm and redistribute the taper so curvature is continuous (G2) from the coaming to the tail. Check with the Stratford criterion — the pressure recovery should satisfy:

$$C_p(x)\ \text{such that}\ \left(C_p \frac{dC_p}{d(x/L)}\right)^{1/2} \le 0.39\left(10^{-6}Re\right)^{1/10}$$

Evaluate this along the top centreline from the Cp plot. If it is violated, the aft body separates before the tail.

### 4.3 Nose
L/D_eq = 4.26 is already close to the minimum-drag optimum for a body of revolution (4–6). **Leave the nose alone** apart from making sure the stagnation region has a minimum radius of 25 mm — a sharper nose gains nothing at this Re and creates a laminar separation bubble at low speed.

### 4.4 Tail truncation
If the moulder cannot pull a fully closed tail, keep the base **sharp-edged and flat** (not rounded). A sharp base fixes the separation line; a rounded truncation lets it wander and adds ~30% to base drag. Base area is small (~0.05 m²) so this is a 1–2 N item.

### 4.5 Interference
Three junctions need attention, and they are where CFD earns its keep:
- **Pod-to-rail:** the 83 mm interference (see [[00 - Master Brief]] §1) creates a channel between pod floor and rail top. Close it with a full-length seal fairing or lift the pod clear.
- **Beam-to-hull:** horseshoe vortex at each of the 4 junctions. Taper the fairing chord to ~60% over the last 150 mm before the hull and add a 40 mm fillet radius.
- **Pod-to-beam:** the forward crossbeam sits under the pod nose. Check whether it is in the pod's stagnation upwash — if so, set the fairing at 2–3° nose-down incidence.

## 5. What to measure in CFD

Report these separately by wall zone so you can see where the drag actually is:

```
/report/forces/wall-forces yes 1 0 0 no    ; drag, X direction
  zones: pod-shell, pod-opening, windscreen,
         beam-fwd-fairing, beam-aft-fairing,
         rail-port, rail-stbd, bracket-*, hull-above-wl
/report/forces/wall-forces yes 0 0 1 no    ; lift, Z direction
/report/forces/wall-moments ...            ; pitching moment about LCG
```

Plus: surface Cp, wall-shear-stress vector field (separation lines), Q-criterion isosurface at Q = 5000 s⁻², and a total-pressure-deficit plane 1.0 m aft of the transom.

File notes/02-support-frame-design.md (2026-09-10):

---
tags: [volare, structures, frame, aluminium]
---

# 02 — Support Frame Design (the rectangular rods)

Parent: [[00 - Master Brief]]

This is the note answering "recommend dimensions and material". Everything below is derived, not assumed.

> **SIZING SUPERSEDED.** Crossbeam stations are fixed by the hulls, and the real load distribution is 79/21 between forward and aft beams, not 50/50. Current sizing is in [[08 - Frame Solution at Fixed Span]]. The load cases, clamp design (§5), joint/racking work (§6) and fairing spec (§7) below all still stand.

> **Partly superseded by the Technical Rules — see [[09 - Rules Audit and Open Questions]] Part A.**

## 1. Load definition

Suspended mass carried by the frame:

| Item | kg |
|---|---|
| Cockpit shell | 30 |
| Pilot | 70 |
| Battery + electronics + seat | 80 |
| **Total suspended** | **180** |

At 3g: **W = 5297 N** total, split equally between the two crossbeams.

Additional cases:
- **LC-R (racking):** one hull on a crest, the other in a trough. Differential hull pitch of 3° over 2.035 m spacing torques the frame. This is the case that sizes the *joints*, not the beams.
- **LC-O (rollover):** inverted, 320 kg all-up. Design contact load on the pod roll structure = 1.5 × 0.5 × 320 × 9.81 = **2354 N**. Handled in [[03 - Composite Structure]] §6.
- **LC-B (battery retention):** treat separately at ≥ 8g in all three axes — cheap to satisfy and it is what "battery stays safe and inert" actually requires. Confirm the MEBC number.

## 2. Crossbeams — sizing

Clear span between hull inner faces = **1581 mm**. Two point loads of 1324 N at ±200 mm from midspan (the rail positions).

$$M_{max} = P\cdot a = 1324 \times 0.5905 = \mathbf{782\ N\!\cdot\!m}$$

$$\delta_{mid} = \frac{Pa(3L^2-4a^2)}{24EI} = \frac{198.9}{EI}$$

| Target | EI required | I for Al (69 GPa) | I for CFRP (100 GPa) |
|---|---|---|---|
| L/300 = 5.3 mm | 37.7 kN·m² | 54.7 cm⁴ | 37.7 cm⁴ |
| L/400 = 4.0 mm | 50.3 kN·m² | 72.9 cm⁴ | 50.3 cm⁴ |

## 3. Rails — sizing

Span between crossbeams **as currently drawn** = 2998 mm. UDL = 883 N/m.

$$M_{max} = \frac{wL^2}{8} = \mathbf{993\ N\!\cdot\!m},\qquad \delta = \frac{5wL^4}{384EI} = \frac{929.3}{EI}$$

| Target | EI required | I for Al |
|---|---|---|
| L/300 = 10.0 mm | 93.0 kN·m² | **134.8 cm⁴** |
| L/400 = 7.5 mm | 124.0 kN·m² | 179.7 cm⁴ |

### 3.1 SUPERSEDED — see [[07 - Why Beam Position Beats Beam Size]] §4

The relocation logic below is sound, but the COMPETR outboard (25 kg + 10 kg trim, ~2800 N thrust, 100 N·m reaction, ±40° steering) means the **aft crossbeam must stay at the stern**. Revised architecture is **three beams**: two light cockpit beams at ~1.8 m spacing (80×40×3) plus a dedicated stern drive beam (120×60×5, closed section, sized for torsion). Read §4 of note 07 before using the table below.

### 3.2 The span principle (still valid)

The aft crossbeam at X = +1942 sits 1.1 m behind the pod tail and carries nothing there. Deflection under UDL scales as WL³ for fixed total load, so shortening the rail span is cubically effective:

| Rail span | EI req (L/300) | Al I req |
|---|---|---|
| 3.00 m (as drawn) | 93.0 kN·m² | 135 cm⁴ |
| 2.40 m | 59.6 kN·m² | 86 cm⁴ |
| **1.90 m** | **37.4 kN·m²** | **54 cm⁴** |
| 1.70 m | 29.9 kN·m² | 43 cm⁴ |

Relocating the crossbeams to roughly X = −1250 and X = +550 (1.80 m apart, bracketing the pilot and battery mass) drops the rail from 120×60×4 to 100×50×3 and saves **~10 kg**. Subject to hull bulkhead positions — get those before committing.

## 4. Recommended sections

Aluminium **6082-T6** (or 6061-T6): E = 69 GPa, ρ = 2700 kg/m³, σ_y = 260 MPa, marine-acceptable with anodising.

| Section h×b×t | I [cm⁴] | A [cm²] | kg/m | Z [cm³] |
|---|---|---|---|---|
| 80×40×3 | 55.9 | 6.84 | 1.85 | 14.0 |
| **100×50×3** | **112.1** | **8.64** | **2.33** | **22.4** |
| 100×50×4 | 144.1 | 11.36 | 3.07 | 28.8 |
| 120×60×4 | 255.2 | 13.76 | 3.72 | 42.5 |
| 150×50×4 | 404.1 | 15.36 | 4.15 | 53.9 |

### Recommendation

| Member | Section | Length | Mass | Utilisation |
|---|---|---|---|---|
| Crossbeam ×2 | **100 × 50 × 3 mm RHS**, tall axis vertical | 2300 mm | 5.37 kg ea | I = 112 vs 55 req → 2.0× |
| Rail ×2 (frame relocated) | **100 × 50 × 3 mm RHS** | 2700 mm | 6.30 kg ea | I = 112 vs 54 req → 2.1× |
| **Frame total** | | | **23.3 kg** | vs 33.0 kg as drawn |

Stress at 3g: crossbeam σ = 34.9 MPa (**FoS 7.5**), rail σ = 23.3 MPa (**FoS 11.1**). Stiffness governs, not strength — which is the correct place to be, because it means the 2× stiffness margin is carrying your racking and rollover cases for free.

**Orientation matters:** 100 tall × 50 wide, *not* the square 104 you have. The tall-narrow section puts material where the bending load is and halves the frontal area presented to the airflow — a 2-for-1.

### Why aluminium over the alternatives

| Material | I req (rail, L/300) | Section needed | kg/m | Verdict |
|---|---|---|---|---|
| **Al 6082-T6** (69 GPa) | 135 cm⁴ | 120×60×4 | 3.72 | **Baseline.** Cheap, clampable, machinable, available in Mumbai |
| GFRP pultruded box (23 GPa) | 400 cm⁴ | 150×75×6 | 4.86 | Heavier despite lower density — E is too low. Reject |
| CFRP (≈100 GPa) | 93 cm⁴ | 100×50×3 | 1.38 | Half the mass. Upgrade path if budget allows |

If you go carbon: **you must electrically isolate it from every aluminium and stainless part.** Carbon is cathodic to aluminium; in salt spray the aluminium will pit within a season. Use 0.5 mm G10 isolation washers and phenolic bushings at every fastener, and a glass ply as the outermost layer of any carbon part.

## 5. Hull clamps — you said "clamped, no hardpoints"

**First check whether you are permitted to drill supplied hulls.** Assume not. That forces a non-penetrating clamp:

**Concept: saddle-and-yoke compression clamp**
- Upper saddle: aluminium plate contoured to the deck camber, **250 × 130 mm footprint**, 8 mm thick, with a 5 mm EPDM or neoprene interlayer
- Lower yoke: a strap or moulded GRP cradle passing under the hull, pulled up by 2 × M10 A4-316 tie-rods per clamp
- Beam sits in a bolted split collar on the saddle so the beam can be indexed fore-aft and rotated for fairing alignment

Bearing check: 1324 N over 250 × 130 mm = **0.041 MPa**. Trivial for GRP — the concern is not crushing but **peel and local deck panel bending**. Hence the large footprint and the elastomer, which spreads load and prevents point contact on a deck stiffener edge.

Friction retention against fore-aft slip: with EPDM on gelcoat, µ ≈ 0.6. Required tie-rod preload per clamp to resist a 3g surge of 1770 N: **F = 1770/0.6 ≈ 2950 N**, i.e. ~1500 N per M10 rod — well within an M10 A4-70 (proof load ~29 kN). Torque to 20 N·m and use nyloc + witness marks.

**Position the clamps over hull internal bulkheads.** Unsupported deck skin under a clamp will creep. Get the bulkhead stations from the organisers.

## 6. Joints and racking stiffness

A four-member ladder frame with bolted corners has poor torsional stiffness — under LC-R the corners rotate and the pod becomes the load path, which you do not want.

Three fixes, use at least two:

1. **Gusseted corner joints.** Replace the 166 × 109 × 162 mm blocks with welded aluminium corner castings or 8 mm gusset plates on both the top and bottom faces of each junction, developing full moment continuity.
2. **Horizontal diagonal bracing.** Two 40 × 40 × 3 RHS diagonals in the plane of the frame, from the forward crossbeam ends to the aft crossbeam centre. Adds ~2 kg, transforms racking stiffness. Cheapest fix available.
3. **Stressed floor panel.** Bolt the pod floor (which is a sandwich panel anyway) to both rails and both crossbeams on a 150 mm bolt pitch through moulded-in inserts. The floor then acts as a shear diaphragm. This is elegant and free in mass — but *only* do it if you use bolts with elastomer grommets, never a bonded aluminium-to-GRP joint (differential thermal expansion is 23 vs 10 µε/K; a 3 m bonded joint over a 30 K swing generates 1.2 mm of differential movement and will crack).

## 7. Beam fairings — the 2.3 kW item

Non-structural shells clamped around the RHS. This is where 77% of your superstructure drag lives.

**Section:** symmetric, 4:1 fineness. For a 50 mm wide beam → **200 mm chord × 50 mm thick**, i.e. a NACA 0025 at 200 mm chord, or simpler: a 60 mm-radius nose, straight taper, sharp 15° trailing edge.

**C_D on thickness-frontal:** 2.05 (bare square) → **0.12** (4:1 strut). Combined with the 104 → 50 mm width reduction, frontal area halves too.

**Construction (wet layup compatible):**
- Split the fairing on the horizontal plane through the beam centre
- 25 mm PVC foam or cork plug, hot-wire or CNC cut to the aerofoil, hollowed to clear the RHS
- 2 × 200 gsm plain-weave glass each half, wet laid over the plug in a female mould
- Join with a 25 mm-wide external glass tape strip on the low-curvature upper surface, or nylon quarter-turn fasteners for removability
- Mass ≈ 1.5 kg per beam per side → ~6 kg total for both beams and both rails

**Details that matter:**
- Chord tapers to 60% over the last 150 mm at each hull junction, with a 40 mm fillet — kills the horseshoe vortex
- Leading edge sealed against the beam so the fairing cannot pressurise internally
- Drain hole 6 mm at the lowest point of each fairing
- Set fairing incidence to 0° after checking the pod's upwash field in CFD (see [[01 - Aerodynamic Redesign]] §4.5)

**Rail fairings:** the rails are axial to the flow, so only the forward 200 mm needs a nose cone — a simple half-ogive cap, 150 mm long, glassed to the rail end. C_D 0.90 → 0.15 on the blunt end. 0.6 kg, 3 N.

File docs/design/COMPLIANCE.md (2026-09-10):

# Monaco Energy Class compliance

Rules: **Monaco Energy Class Technical Rules, Version 2026.1**, issued 08/09/2025
by the Yacht Club de Monaco. Copy held in `04_data/`.

Run the live check:

```bash
matlab -batch "addpath(genpath(pwd)); P50B_MonacoCompliance"
```

`TEST_ALL` fails if any quantifiable rule is violated.

**94 checks: 55 pass, 0 violations, 14 to action, 24 on the inspection
checklist.** 70 of the 94 are computed; the rest are physical or procedural.

To push the result to Mission Control's Compliance tab:

```bash
matlab -batch "addpath(genpath(pwd)); P50B_ExportCompliance"
python tools/build_mission_control.py
```

---

## How a rule becomes a check

Most of the 2026 rules are a number and a direction — *at least 30 mm*, *no
more than 50 mm*, *at least 500 cm²*. They are checked at scrutineering by a
person with a tape measure, which used to mean they sat on a checklist here and
nothing more.

That was a missed opportunity. A rule with a number in it is a number the team
has to commit to **before** the tape measure comes out. The `cockpit` section
of `params/volare_params.json` records the intended value for each one, and the
compliance module compares it against the limit and reports the margin.

This turns "verify at inspection" into "we intend 40 mm against a 30–50 mm
window, and here are the four items with less than 5% margin". It is not
evidence — it is a design the team has written down and can be held to. When a
value is measured on the boat its tag changes from `DESIGN_CHOICE` to
`MEASURED` and the same check becomes evidence.

The comparison helpers are deliberately three, not one:

| | |
|---|---|
| `addMin` | at-least rules; flags anything with under 5% margin |
| `addMax` | at-most rules |
| `addExact` | rules stating a **value**, like the 90 mm yellow circle — meeting it exactly is compliance, not a thin margin, so it does not nag |

Getting the direction backwards is the one mistake in a compliance checker that
really matters: a reversed comparison reports PASS on a boat that fails. Taking
the value, the limit and the direction once, in a helper, is how that is
avoided.

---

## The two rules that reshaped this design

### ENERGY_REQ_188 — motor nominal power ≤ 25 kW

> *"The total nominal power consumption of the motor(s) shall not exceed 25 kW."*

New for 2026 (see the change history on page 5 of the rules).

**The Competr outboard is rated 26.9 kW nominal and 42 kW peak. As delivered it
does not comply.** The hardware is 1.9 kW over the limit on its nominal rating
alone.

The fix is a hard cap in the inverter configuration, and it is enforced
throughout this model rather than merely flagged:

| Where | What it does |
|---|---|
| `P50B_MotorData` | `ConfiguredPowerLimit_W = 25 kW` |
| `P50B_DrivetrainModel` | Bisects on shaft power so motor electrical input never exceeds the cap; reports `PowerLimit.Active` |
| `P50B_InverterData` | All current sizing derives from 25 kW, not 42 kW |
| `P50B_MissionProfile` | Shaft-power cap derived from the 25 kW electrical limit |
| `P50B_Busbars` | Operating points rebased on the cap; 42 kW retained only as a fault case |
| `TEST_ALL` | Asserts a 60 kW demand is capped, not delivered |

**Read carefully: the cap is on electrical power *consumed*, not shaft power.**
Setting a 25 kW cap at the propeller shaft would demand about 26.9 kW of motor
input and break the rule. The model applies it at the motor's electrical
terminals, which is the stricter and correct reading.

With the cap active, a 25 kW shaft request yields **23.1 kW at the shaft** and
exactly 25.0 kW of motor input.

**Still to do:** compliance depends entirely on the derate. Get a written
statement from Competr confirming the unit can be limited to 25 kW nominal, and
be able to show the setting in the inverter configuration at scrutineering.

#### A side benefit

Capping at 25 kW roughly halves the inverter the drivetrain needs:

| Sized against | Device current rating required |
|---|---|
| 42 kW hardware peak | 725 A |
| 25 kW rule cap | **418 A** |

That is a materially cheaper, smaller and cooler inverter.

---

### ENERGY_REQ_7 — stored energy under 10 kWh

> *"At any moment, the maximum energy stored by a boat shall remain under 10 kWh."*

The rule prescribes the calculation exactly, with a battery energy factor of 1.0:

```
quantity of cells × cell nominal voltage × cell nominal capacity
      546         ×        3.6 V         ×        5.0 Ah        = 9828 Wh
```

| | |
|---|---|
| Stored energy | **9828 Wh** |
| Limit | 10 000 Wh |
| Margin | **172 Wh — 1.72%** |
| Maximum cells this rule permits | **555** |

**COMPLIANT, but with almost no margin.** You have 9 cells of headroom against a
546-cell pack.

Two things to be careful about:

1. **Nominal values only.** The rule says explicitly *"Only nominal/typical values
   will be considered (not minimal / maximal)"*, so the 5.0 Ah typical applies,
   not the 4.85 Ah datasheet minimum. That works in your favour here.

2. **The rule text says "cell nominal current"** where it can only mean capacity
   in Ah — that is the sole reading that yields an energy. If the Technical
   Committee interprets it differently, the number changes. Worth confirming at
   registration, given how thin the margin is.

The calculation must be submitted to the Technical Committee before the event.

---

## Rules that pass

| Requirement | Result |
|---|---|
| ENERGY_REQ_7 | 9828 Wh of 10 000 Wh |
| ENERGY_REQ_23 — cells within datasheet ratings | 17.9 A/cell at the bus maximum, against a 60 A rating — 30% utilisation |
| ENERGY_REQ_57 — wire gauge | 150 mm² cable, 459 A derated, against 385 A worst legal draw |
| ENERGY_REQ_59 — protection coordination | 400 A fuse below both the 450 A busbar and 459 A cable |
| ENERGY_REQ_93 — exposed parts below 60 °C | Highest modelled steady cell temperature **35 °C** (was 54 °C — see below) |
| ENERGY_REQ_154 — steering ≥40° each side | Competr ±40° — *exactly at the limit, no margin* |

### How ENERGY_REQ_59 drove the whole HV path

> *"The continuous current rating of the overcurrent protection shall not be
> greater than the continuous current rating of any electrical component."*

This is easy to get backwards. The instinct is to size the fuse *above* peak
load; the rule sizes it *below* the weakest conductor. Both must hold at once,
which pins the design:

```
385 A worst legal draw  <  400 A fuse  ≤  450 A busbar  ≤  459 A cable
```

Getting there required three changes from the original design:

| Component | Was | Now | Why |
|---|---|---|---|
| HV cable | 70 mm² (214 A derated) | **150 mm²** (459 A) | 70 mm² could not carry the current at all |
| Series busbar | 20 × 2 mm (40 mm²) | **30 × 3 mm** (90 mm²) | Sized against 267 A, not the real worst case |
| Collector rail | 6 × 1.5 mm (9 mm²) | **8 × 1.5 mm** (12 mm²) | Became the binding constraint once the links were fixed |
| Fuse | 500 A | **400 A** | 500 A violated REQ_59 against every conductor |

Note the sizing driver is **25 kW at the 65 V minimum bus = 385 A**, not 25 kW at
nominal voltage. The cap fixes power, so current is highest when the pack is
nearly empty.

### Why ENERGY_REQ_93 moved from 54 °C to 35 °C

Not because the design changed. Because the model was cooling the wrong pack.

`P50B_ThermalDesign` carried a hard-coded 5.0 K/W cell-to-coolant resistance,
with a comment describing conduction *"through holder and TIM"* from the bottom
of the cell. That is an accurate description of the flat, side-cooled layout
this project started with and then abandoned. The pack is cooled on the cell
**ends** now, both of them, through three cold plates, and the resolved value
is **0.909 K/W** — the figure the README had been quoting all along.

The mission integrator drove cell temperature through the stale number, so
every MATLAB temperature rise was about 5.5× too pessimistic. Python had the
right value; nothing compared them.

`tools/crosscheck.py` compares it now.

### Rules the boat model settled

ENERGY_REQ_37 and ENERGY_REQ_32 used to be checklist items, because MATLAB had
no boat in it. It has one now.

| Requirement | Result |
|---|---|
| **ENERGY_REQ_37** — at least 3 knots | 403 W at the shaft, **1.8%** of the ceiling. Top speed 22.1 knots. |
| **ENERGY_REQ_32** — forward and reverse | 612 N astern against 33 N of resistance at 2 knots, **18× margin** |

The Technical Committee still judges manoeuvrability by watching the boat at
the sea certification test. But a design that cannot make three knots on paper
will not make them on the water either, and finding that out in Monaco is
expensive.

See [`HYDRODYNAMICS.md`](HYDRODYNAMICS.md).

---

## Items needing action

These are not design faults. They are gates that must be cleared.

| Requirement | Action |
|---|---|
| **ENERGY_REQ_187** | Pack reaches 109.2 V at full charge. Any system above 100 V needs **Technical Committee approval during registration**. Without it the boat cannot race. |
| **ENERGY_REQ_191** | Everyone working on the pack needs a **high voltage training certificate**. Checked at technical inspection. |
| **ENERGY_REQ_188** | Obtain Competr's written confirmation of the 25 kW derate. |
| **ENERGY_REQ_68** | Set the BMS temperature warning to **63 °C** (90% of the 70 °C cell maximum). |
| **ENERGY_REQ_67** | Confirm the BMS temperature channel reaches the pilot display, including the telemetry battery. |
| **ENERGY_REQ_182** | Add a **3.2 mm pass-through** so the organiser's sensor can reach the cells at the pack core. The three empty slots in the 4×4 grid give a natural route. |
| **ENERGY_REQ_58** | Confirm the physical fuse sits immediately after the pack terminals, and that the telemetry battery has one too. |

### Mass — ENERGY_REQ_48 and ENERGY_REQ_135

> *"The overall weight excluding the hulls shall not exceed 250 kg."*
> *"The boat will be weighted with the hulls and the pilot. The hulls are
> supposed to be 65 ± 1 kg."*

So the test on the day is `(scales, hulls and pilot included) − 65 ≤ 250`, and
**the pilot counts against the 250**. That is easy to get wrong in the
optimistic direction, because "excluding the hulls" reads like an invitation to
exclude the pilot too. It is not.

`P50B_MassBudget` builds it line by line:

| Item | kg | Source |
|---|---|---|
| Pilot, ready to sail | 80.0 | assumption |
| Battery pack | 51.6 | model |
| Cockpit structure | 32.0 | allowance |
| Outboard | 25.0 | datasheet |
| Trim assembly | 10.0 | datasheet |
| Cooling system | 7.0 | allowance |
| Inverter / ESC | 6.5 | allowance |
| Steering and controls | 6.0 | allowance |
| Safety equipment | 6.0 | allowance |
| Contingency | 6.0 | reserve |
| Seat | 4.5 | allowance |
| HV harness and switchgear | 4.0 | allowance |
| LV system | 3.5 | allowance |
| Beam clamps and fasteners | 3.0 | allowance |
| Organiser equipment | 2.5 | allowance |
| **Excluding hulls** | **247.6** | limit 250 |
| **Margin** | **2.4 kg (1.0%)** | |

The scales will read **312.6 kg** with the 65 kg of hulls.

**This is the second tightest constraint in the project after stored energy,
and unlike stored energy it is made of two dozen estimates rather than one
exact calculation.** 30% of the budget is allowances rather than weighed parts.
An overweight boat is not allowed in the water at all.

> **Action:** put the pack, the cockpit shell and the outboard on a scale as
> soon as each exists.

ENERGY_REQ_135 requires the pilot at 60 kg minimum ready to sail — with
overalls, helmet, lifejacket, shoes and communications. At 80 kg no ballast is
needed, but every kilogram a lighter pilot is under 60 becomes ballast that
also counts against the 250. Size it on the **lightest** pilot entered, as the
rule says. Run `P50B_MassBudget("PilotMass_kg", 58)` to see the effect.

The same figure is the boat's **floating mass**, which is what the
hydrodynamics needs. `boat.displacement_kg` was 250 kg — the rule's limit,
mistaken for the displacement, in both codebases independently.

---

## Telemetry — Annex III and Annex IV

The organiser requires a REST/JSON feed of pack temperatures, voltage, current
and position, and a 10–28 V / 30 W supply on a specified Amphenol LTW connector
to power their monitoring device.

Annex III says the API *"will be confirmed in February 2026"* and gives an
example payload. That example is treated as the contract until the final one is
published, so confirming it should be a one-line change rather than a rewrite.

Mission Control's **Compliance** tab builds the payload live from the running
boat, so the format can be checked against the organiser's endpoint before the
event rather than in the paddock. The three temperature channels carry hottest
cell, coldest cell and coolant outlet — the spread, not only the peak, because
a single maximum says the pack is fine right up until it is not.

> One thing to know before anyone "fixes" it: the Annex III example puts `lat`
> at 7.44 and `lon` at 43.74, which is Monaco with the two fields swapped. The
> payload follows the **example**, not the convention, because the organiser's
> parser is what has to accept it.

---

## Physical and procedural checklist

Twenty-four requirements cannot be evaluated from a model at all — bulkhead
fire rating, kill-cord behaviour, sharp edges, whether a component is actually
fixed down. `P50B_MonacoCompliance` lists them so they are not quietly
forgotten. Highlights for the pack in particular:

- **ENERGY_REQ_25** — energy container at least 500 mm from the pilot (relaxed
  from 1 m for 2026)
- **ENERGY_REQ_155** — container overpressure valve, certified and adequately
  sized, oriented aft
- **ENERGY_REQ_56** — fire extinguisher port on the **port** side of the container
- **ENERGY_REQ_189** — external charging interface so the battery can be recharged
  **without opening the container** (new for 2026)
- **ENERGY_REQ_61** — all wiring outside the enclosure orange
- **ENERGY_REQ_60** — no live part touchable with a 100 mm long, 6 mm probe
- **ENERGY_REQ_62** — electronics in an IP56 watertight, cooled compartment
- **ENERGY_REQ_55** — cable pass-throughs fitted with grommets
- **ENERGY_REQ_50/52** — bulkhead isolates the pilot and contains an explosion
- **ENERGY_REQ_181** — ESC input power wired for the organiser's sensing device

The following used to be on this list and are now **computed against a declared
intent**, with their margins reported: REQ_25, 38, 44, 45, 46, 47, 49, 51, 63,
71, 76, 77, 78, 79, 85, 96, 99, 101, 102, 103, 106, 137, 141, 142, 150, 151,
171, 172, 173, 174, 175, 182, 184, 185, 186.

Four of them have under 5% margin and are flagged for action: the four
high-visibility tape areas, the 1 kg fire extinguisher, and the two-clamps-per-beam
count. All are cheap to increase and none needs a design change.

---

## What a pass here does and does not mean

`P50B_MonacoCompliance` returning zero violations means **the rules this model
can evaluate are satisfied**. It is not a statement that the boat is compliant.

There are three tiers of confidence in the 94 checks, and they are not
interchangeable:

| Tier | Count | What a PASS means |
|---|---|---|
| **Computed** | ~35 | Derived from the model. Stored energy, currents, temperatures, speed, mass. As good as the model. |
| **Declared** | ~35 | Compared against a value the team wrote down. Says the *design* complies, not the boat. |
| **Checklist** | 24 | Not evaluated at all. Listed so it is not forgotten. |

A declared check passing is worth something — it means somebody chose a number
and it clears the rule — but it is not the same as a measurement. Replace the
`DESIGN_CHOICE` tags with `MEASURED` ones as the boat gets built, and the same
94 checks become progressively more like evidence.

Roughly a quarter of the technical rules are settled at scrutineering, not in
MATLAB, and the Technical Committee is the authority on all of them.

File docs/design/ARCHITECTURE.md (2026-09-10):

# Architecture

How the modules fit together, and why the project is arranged this way.

---

## Data flow

```
                        P50B_CellData
                    (datasheet + OCV + DCIR)
                              |
        +---------------------+---------------------+
        |                                           |
   P50B_Geometry                              P50B_21P
  (all dimensions)                                  |
        |                                     P50B_13S21P
   P50B_GroupLayout                                 |
  (26 groups, 546 cells,                      P50B_26S21P
   pack envelope)                                   |
        |                                    Simscape Battery
   P50B_Busbars                               pack object
  (joints, rails, links,                            |
   ampacity, loss)                            buildBattery
        |                                           |
        +-------------------+                  output/*.slx
                            |
   P50B_MotorData ----+     |
   P50B_InverterData -+     |
   P50B_HarnessData --+-----+
   P50B_AuxiliaryLoads|     |
                      |     |
                 P50B_DrivetrainModel
              (solves one operating point)
                            |
              +-------------+-------------+
              |                           |
      P50B_RunMission            P50B_ThermalDesign
    (time-stepped mission)      (heat and temperature)
              |                           |
              +-------------+-------------+
                            |
              +-------------+-------------+
              |                           |
      P50B_Verification         P50B_MonacoCompliance
     (engineering checks)          (rules checks)
                            |
                 P50B_ProvenanceReport
                (which numbers are real)
```

Everything above is driven end to end by `P50B_26S21P_MASTER`.

---

## Folder layout

| Folder | Contents | Key idea |
|---|---|---|
| `00_common/` | Provenance helpers, project root | Every parameter carries its source |
| `01_cell/` | Cell definition, OCV, DCIR | Single source of truth for the cell |
| `02_pack/` | Simscape Battery construction | Builds the generated library |
| `03_mechanical/` | Geometry, layout, busbars | Single source of truth for dimensions |
| `04_data/` | Datasheets, measured CSVs | Drop measured data here; it loads automatically |
| `05_tests/` | Test scripts | `TEST_ELECTRICAL`, busbar sizing study |
| `06_drivetrain/` | Motor, inverter, harness, loads, chain solver | Where the 25 kW cap is enforced |
| `07_simulation/` | Mission profiles, time-stepped run | Energy and thermal over a mission |
| `08_compliance/` | Monaco rules check | Traceable to ENERGY_REQ numbers |
| `docs/` | This documentation | |
| `output/` | Generated CSV, MAT, SLX | Safe to delete; regenerated on every run |

---

## Design rules the project follows

### One source of truth per quantity

`P50B_Geometry` owns every dimension. `P50B_CellData` owns every cell property.
Nothing is restated anywhere else — `P50B_Geometry` even reads its cell
dimensions from `P50B_CellData` rather than repeating them, and
`P50B_MechanicalLayout` asserts that the cell struct it is handed matches the one
the geometry was built from.

This was not previously true. The project had **two independent layout
generators** with different origins, different Z datums, different group
ordering, and different output field names. `P50B_Verification` read fields that
only one of them produced, so it could not run. The duplicate implementation is
gone; `P50B_MechanicalLayout` is now a thin compatibility wrapper that delegates
to `P50B_GroupLayout`.

### Provenance on every number

No value that feeds a calculation is a bare literal. Each is wrapped by
`P50B_Param` with a unit, a source tag, and usually a note explaining the choice.
`P50B_ProvenanceReport` walks all of it and prints what is datasheet-backed,
what is estimated, and what is invented.

The model currently contains **no `PLACEHOLDER` parameters**, and `TEST_ALL` fails
if any are introduced. See `DATA_PROVENANCE.md`.

### Options, not edits

Every analysis function takes `"Plot"` and `"Verbose"` options so it can run
silently inside a sweep. Expensive objects — geometry, layout, busbars — are
built once and passed in, rather than rebuilt per call. `P50B_RunMission` builds
them once for thousands of time steps.

### Assertions where a bug would be invisible

Cell interference, group population, layer balance, OCV monotonicity, DCIR grid
completeness, series-path adjacency, and mission energy balance are all asserted.
These catch the class of error that otherwise produces a plausible-looking but
wrong pack.

The energy balance check is the strongest of them: shaft energy plus every
modelled loss must equal energy drawn from the cells, to within 0.5%. It
currently closes to 0.0000%.

---

## The chain solver

`P50B_DrivetrainModel` is the centre of the project. Given a shaft power demand,
motor speed, SOC and cell temperature, it works backwards through every loss:

```
propeller <- gearbox <- motor <- inverter <- DC link
          <- harness <- pack terminals <- series links
          <- collectors <- joints <- cells
```

Two things make it worth reading:

**The power cap is enforced, not reported.** Monaco ENERGY_REQ_188 limits motor
electrical input to 25 kW. Motor input rises monotonically with shaft power at
fixed speed, so the solver bisects to find the largest permissible shaft power
and reports `PowerLimit.Active`. A 60 kW demand produces a capped operating
point, not a 60 kW one.

**The pack solve is closed-form.** Pack current appears on both sides of the
problem: current causes voltage sag, and sag raises the current needed for a
given power. Rather than iterate, the terminal condition

```
I × (V_ocv − I·R_total) = P_bus
```

is solved directly as a quadratic. The physical root is the smaller one. A
negative discriminant means the demanded power exceeds what the pack can deliver
at this SOC and temperature — that is reported as infeasible, not silently
clamped.

---

## The serpentine layout

Groups are numbered along a boustrophedon path so that G(n) and G(n+1) are always
physically adjacent. Every one of the 25 series links is then a short hop rather
than a run across the pack.

Layer 2 is traversed in reverse row order *and* with its column direction chosen
so that its first group lands directly above the last group of layer 1. That
makes the inter-layer link a short vertical hop of 80 mm instead of a diagonal
run.

This was a real bug found by the layout's own adjacency assertion: layer 2
originally started at column 1 while layer 1 ended at column 4, so the G13→G14
link spanned three group pitches. `Layout.AllStepsAdjacent` now guards it.

Odd groups are positive-down, even groups positive-up, so every series link joins
two terminals on the same face, alternating between the top and bottom of the
pack. With 26 groups this also puts both pack terminals on the top face, so both
HV cables exit the same side.

Result: 3.71 m total series path, longest step 175 mm, all 25 links adjacent.

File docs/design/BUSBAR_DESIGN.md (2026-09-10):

# Interconnect design

Everything between a cell terminal and the pack terminal: welds, collector rails,
manifolds and series links.

Model: `03_mechanical/P50B_Busbars.m`
Sizing study: `05_tests/Test_BusbarSizing.m`

---

## Result

| | |
|---|---|
| Total interconnect resistance | **1.538 mΩ** |
| Copper mass | 6.21 kg |
| Voltage drop at 385 A | 0.59 V (0.63% of nominal) |
| Loss at 385 A | 228 W |

### Where the resistance is

| Contributor | Resistance | Share |
|---|---|---|
| Series links (25) | 0.94 mΩ | **61%** |
| Collector rails + manifolds | 0.34 mΩ | 22% |
| Cell-to-busbar joints (1092) | 0.25 mΩ | 16% |

---

## Three resistances in series, not one

The previous model computed collector rail resistance only. That understated the
total by roughly a factor of two, because it omitted the two contributors that
sit either side of it.

### 1. Cell-to-busbar joints — the commonly forgotten one

Every cell connects to its collector through a joint at each end. With 546 cells
that is **1092 joints and 2184 welds**, and each one is in series with a cell.

```
R_per_cell  = jointsPerCell × (R_weld / weldsPerJoint)
R_per_group = R_per_cell / 21          (cells are in parallel)
R_total     = R_per_group × 26
```

At an assumed 0.2 mΩ per weld this comes to 0.25 mΩ — **16% of the total, and
comparable to the collector rails themselves**. It is the term most often left
out of first-pass models, which is why those models come out optimistic.

It is also the cheapest thing on this page to measure: a four-wire measurement
across one welded joint on a scrap cell would move it from `ASSUMPTION` to
`MEASURED`.

### 2. Collector rails — centre-fed, so not simply I²R

Each row of 7 cells feeds a rail that is collected at the centre. Segments nearer
the centre carry more current, so the loss is not the group current squared times
the rail resistance.

Numbering columns outward from the centre, each half carries 3i, 2i, i, giving a
loss coefficient of

```
2 × (3² + 2² + 1²) = 28
```

in units of i²·R_segment. The model computes this coefficient from the group
shape rather than hard-coding 28, so it stays correct if the group is ever
reshaped.

The equivalent resistance referred to group current is exact for a linear
network, not an approximation:

```
R_eq = Q_total / I_group²
```

### 3. Manifold

Three row rails feed a terminal at the centre row. The outer two rows carry their
full current one row pitch to reach it. Modelled with its own wider section
(12 × 1.5 mm) because it carries more than a row rail does.

---

## Copper at temperature, not at 20 °C

Resistivity is evaluated at **60 °C**, the assumed busbar operating temperature:

```
ρ(T) = ρ₂₀ × (1 + 3.93e-3 × (T − 20))
```

That is **15.7% more resistance** than the handbook 20 °C value. Busbars in a
sealed pack run hotter than people expect, and using the cold value quietly
flatters every loss number downstream.

---

## Ampacity is the constraint that actually rules options out

Resistance is only half of sizing. A conductor also has to survive the current
thermally. The model applies two limits:

| Duty | Limit | Rationale |
|---|---|---|
| Continuous | 5.0 A/mm² | Sustained current in still air with limited convection |
| Peak | 8.0 A/mm² | Momentary; needs a demonstrated short duty cycle |

These are engineering rules of thumb, not standards, and they are recorded as
such.

### The sizing driver is not what you would guess

The Monaco rules cap motor power at 25 kW. Power is fixed, so **current is highest
when the pack is nearly empty**:

```
25 kW ÷ 65 V minimum bus = 385 A
```

Not 25 kW ÷ 93.6 V = 267 A. Sizing against the nominal-voltage figure understates
the requirement by 44%, and that is exactly what the original design did.

### Operating points

| Case | Duty | Current | Loss | Links | Rails | OK |
|---|---|---|---|---|---|---|
| Monaco cap, nominal V | Continuous | 267 A | 110 W | 3.0 | 3.2 A/mm² | ✓ |
| **Monaco cap, minimum V** | Continuous | **385 A** | 228 W | 4.3 | 4.6 A/mm² | ✓ |
| Competr hardware continuous | Continuous | 375 A | 216 W | 4.2 | 4.5 A/mm² | ✓ |
| FAULT: cap failure at 42 kW | Peak | 646 A | 642 W | 7.2 | 7.7 A/mm² | ✓ |

The last row is not an operating point — the inverter is hard-capped at 25 kW.
It is retained to confirm the interconnect survives long enough for the fuse to
clear if the cap ever fails.

---

## What changed, and why

| Component | Was | Now | Reason |
|---|---|---|---|
| Series link | 20 × 2 mm (40 mm²) | **30 × 3 mm (90 mm²)** | 40 mm² ran at 9.4 A/mm² at the real worst case |
| Collector rail | 6 × 1.5 mm (9 mm²) | **8 × 1.5 mm (12 mm²)** | Became the binding constraint once the links were fixed |

The rail change is worth noting: fixing the series links exposed the rails as the
next limit. The rail segment beside the centre feed carries three cells' worth of
current — 55 A at the worst legal case — which needs 11 mm² at 5 A/mm². 9 mm²
was not enough.

Both are `DESIGN_CHOICE` parameters in `P50B_Geometry`, so they can be revisited.

---

## Routing factor

Straight-line centre-to-centre distance understates a real busbar, which must
clear cell tops and include bend radii. A **1.15 routing factor** is applied to
every series link length. It is an assumption and it moves the total resistance
proportionally — worth replacing with routed lengths once the busbar is drawn.

---

## What is not modelled

- **Skin and proximity effect.** Irrelevant at DC, but the ripple current from a
  10 kHz inverter is not DC. Second-order at these sections.
- **Busbar self-heating feedback.** Conductor temperature is an input, not a
  solved state. At 228 W spread over 6.2 kg of copper the steady rise is modest,
  but a proper thermal solve would close the loop.
- **Current sharing between the 21 parallel cells.** The model treats a group as
  a lumped equivalent. In reality cells at the ends of a row see slightly more
  resistance than those at the centre, so they share slightly less current. This
  is the main reason `ModelResolution="Detailed"` is kept on the Simscape
  parallel assembly.
- **Fuse element resistance rise.** Modelled as a cold value; it climbs
  substantially as the element heats.

---

## Sizing study

`Test_BusbarSizing` sweeps width and thickness against the real link lengths from
the layout — not a placeholder length — evaluates every operating point, and
reports which geometries satisfy loss, voltage drop and current density together.
It then names the lightest acceptable option.

It also prints the comparison that matters: what a geometry sized against 25 kW
at *nominal* voltage looks like when the pack is actually empty.

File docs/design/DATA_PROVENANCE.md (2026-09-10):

# Data provenance

Which numbers in this model are real, which are estimates, and how to replace
the estimates.

Run `P50B_ProvenanceReport` for the live version of this, generated from the
code itself. This document explains the reasoning behind the tags and gives the
measurement procedure for each gap.

---

## Why this exists

A model that mixes datasheet values with invented ones, without distinguishing
them, produces results that look equally authoritative regardless of whether
they mean anything. The previous revision of this project had a cell resistance
of `0.012` and a thermal resistance of `1.0` with `% Placeholder ONLY` beside
them — honest in the source, invisible in the output.

Every parameter now carries a source tag, and the report prints a warning block
for anything unverified.

---

## Source tags

| Tag | Confidence | Meaning |
|---|---|---|
| `MEASURED` | 1 | Measured in-house on this project's hardware |
| `DATASHEET` | 2 | Direct from a manufacturer datasheet in `04_data/` |
| `PUBLISHED_TEST` | 3 | Third-party published characterisation |
| `CALCULATED` | 4 | Derived from other parameters in this project |
| `DESIGN_CHOICE` | 5 | A value the team selected, not a physical constant |
| `ASSUMPTION` | 6 | Engineering estimate, defensible but unverified |
| `PLACEHOLDER` | 7 | Invented to let the model run — **not quotable** |

`TEST_ALL` fails if any `PLACEHOLDER` parameter exists.

---

## What is solid

### Cell — Molicel INR-21700-P50B

All from the manufacturer datasheet:

| Parameter | Value |
|---|---|
| Typical capacity | 5.0 Ah |
| Minimum capacity | 4.85 Ah |
| Nominal voltage | 3.6 V |
| Charge voltage | 4.2 V |
| Discharge cut-off | 2.5 V |
| Max continuous discharge | 60 A (12 C, to a 70 °C cut-off) |
| Max charge current | 25 A (5 C) |
| AC impedance at 1 kHz | 6.5 mΩ |
| DC internal resistance | 12.8 mΩ |
| Nominal energy | 18 Wh |
| Envelope | 21.55 mm × 70.15 mm |

**A warning about the two impedance figures.** The 6.5 mΩ AC value is a
production screening measurement. It is roughly half the DC value and it must
never be used for loss or thermal work — doing so halves your predicted heat.
The model records both specifically so the wrong one cannot be picked up by
accident.

### Drivetrain — Competr outboard

All from `New_Datasheet Competr_0625.pdf`:

| Parameter | Value |
|---|---|
| Nominal power | 26.9 kW (40 HP) |
| Maximum power | 42 kW |
| Maximum torque | 100 Nm |
| Motor type | Axial-flux PMSM, water cooled |
| Mass | 25 kg (outboard), +10 kg trim assembly |
| Battery configuration | 26S |
| Bus nominal / maximum | 96 V / 109 V |
| Maximum continuous current | 375 A |
| Aux DC/DC | 12 V, 1 kW |
| Trim / steering pump drivers | H-bridge, 12 V, 40 A each |
| Bilge / cooling pump drivers | Low side, 12 V, 15 A each |
| Position sensor | SSI absolute encoder |
| Motor temperature sensor | Analog PTC |
| Trim range | −5° to +30° |
| Steering range | −40° to +40° |

---

## What needs measuring

Ordered by how much the result depends on it.

### 1. Inverter — not selected at all

The Competr datasheet section 5 lists the inverter as *"On request"* with the
note *"Higher current rating required to reach full output power"*.

Every inverter loss number in this model is against a representative 650 V SiC
module, not a real part. `P50B_InverterData` derives what the real part must
satisfy:

| Requirement | Value | Driven by |
|---|---|---|
| Blocking voltage | ≥147 V | 109 V bus × 1.35 overshoot |
| DC current, nominal bus | 267 A | 25 kW cap ÷ 93.6 V |
| DC current, worst case | 385 A | 25 kW cap ÷ 65 V minimum bus |
| Device current rating | ≥418 A | peak phase current × 1.25 margin |

All of these follow from the **25 kW Monaco cap**, not from the outboard's 42 kW
hardware peak, which is not a permitted operating point. Sizing against 42 kW
instead would demand a 725 A device.

**To replace:** select a device and substitute its `Rds_on`, `Eon`, `Eoff`,
`Erec`, reference test conditions and thermal resistances.

### 2. Motor electrical parameters

Not in the datasheet. Currently `ASSUMPTION`:

- Pole pairs (10)
- Ld (85 µH), Lq (95 µH)
- Rated peak phase current (400 A)
- Iron loss, windage and constant-loss coefficients
- Peak efficiency (95.5%)
- Gearbox ratio (2.0) and efficiency (97%)
- Maximum speed (4000 rpm)

Flux linkage and phase resistance are both *back-calculated* rather than assumed
independently:

- **Flux linkage** from the 100 Nm torque rating via `T = 1.5·p·λ·Iq`, so torque,
  current and flux stay mutually consistent.
- **Phase resistance** (1.96 mΩ at 20 °C) from the peak-efficiency target, so the
  loss model actually reproduces the efficiency the data struct claims.

An earlier draft assumed 8 mΩ phase resistance *and* separately declared 95.5%
efficiency. The two contradicted each other — the loss model produced 89% — and
nothing caught it. The assumption is now the efficiency, which is the honest
place for it.

Both inherit the uncertainty of the pole-pair and rated-current assumptions.

**To replace:** ask Competr for pole pairs, Ld, Lq, permanent-magnet flux
linkage, phase resistance at 20 °C, gearbox ratio, and an efficiency map. This
single request would move most of the motor model to `DATASHEET`.

### 3. Cell OCV curve

One anchor point is real (4.2 V at 100% SOC). The rest is a representative NMC
21700 shape, tagged `ASSUMPTION`.

**To replace:** run a C/20 or slower discharge, or a GITT pulse-relaxation
sequence. Write:

```
04_data/P50B_OCV_SOC.csv
```

with columns `SOC` (0 to 1) and `OCV_V`, strictly increasing in both. The model
loads it automatically and reports the source as `MEASURED`. No code change.

The curve must be monotonic — `P50B_OCV` asserts this, because a non-monotonic
OCV makes the inverse SOC(OCV) map ill-posed and produces silent nonsense.

### 4. Cell DCIR surface

Anchored at the datasheet 12.8 mΩ (50% SOC, 25 °C). Variation around that anchor
uses typical NMC multipliers:

| Temperature | Multiplier vs 25 °C |
|---|---|
| −10 °C | 3.00 |
| 0 °C | 2.10 |
| 10 °C | 1.45 |
| 25 °C | 1.00 |
| 40 °C | 0.82 |
| 55 °C | 0.75 |

| SOC | Multiplier vs 50% |
|---|---|
| 5% | 1.55 |
| 10% | 1.32 |
| 20% | 1.12 |
| 50% | 1.00 |
| 90% | 1.02 |
| 100% | 1.08 |

Independent bench testing has reported P50B units at or below 19 mΩ, which is
consistent with this surface at the cold and low-SOC corners.

**To replace:** run an HPPC pulse sequence across SOC and temperature. Write:

```
04_data/P50B_DCIR_SOC_T.csv
```

with columns `SOC`, `Temp_C`, `DCIR_Ohm` on a full rectangular grid. The model
asserts the grid is complete — gaps are rejected rather than interpolated over.

### 5. Cell-to-coolant thermal resistance

Assumed **5.0 K/W per cell**. Published values for bottom-cooled 21700 cells
through a holder and thermal interface range from 3 to 8 K/W. That factor of
2.7 propagates directly into every steady-state temperature in the model.

**To replace:** build a prototype module, apply a known current, measure cell
surface temperature and coolant inlet/outlet, and solve for the resistance.

### 6. Weld resistance

Assumed **0.2 mΩ per weld**, 2 welds per joint, 2 joints per cell.

This matters more than it looks: there are **1092 joints and 2184 welds** in the
pack, and they contribute a large share of total interconnect resistance —
comparable to the collector rails themselves. It is the term most often omitted
from first-pass models, which is why those models are optimistic.

**To replace:** four-wire measurement across a sample welded joint on a scrap
cell. Cheap and quick, high value.
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

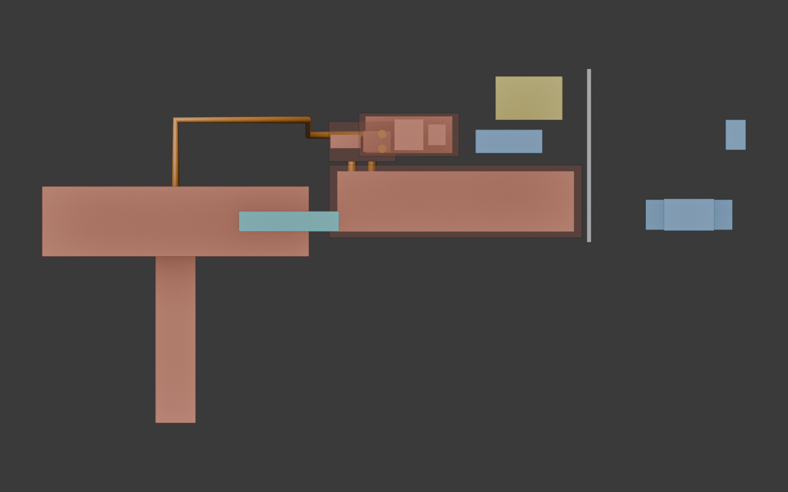
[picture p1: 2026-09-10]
cad/out/figures/side_starboard.png

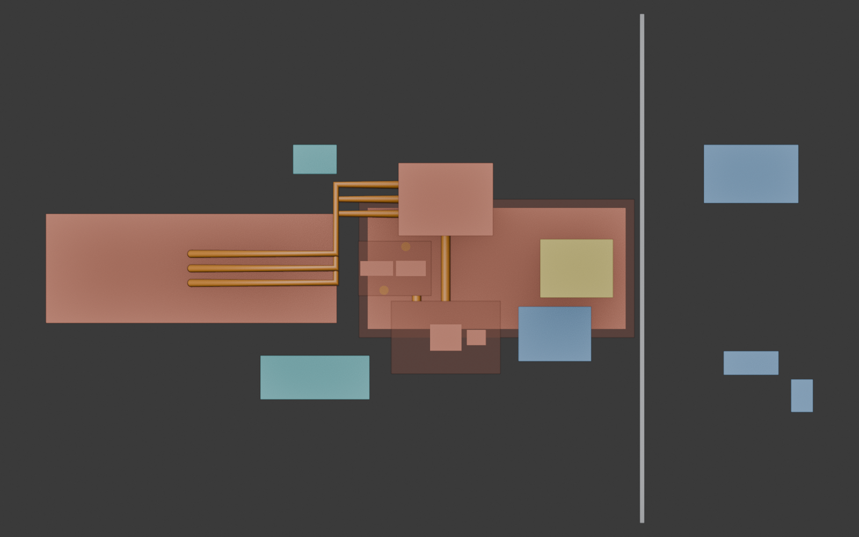
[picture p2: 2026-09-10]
cad/out/figures/plan_from_above.png

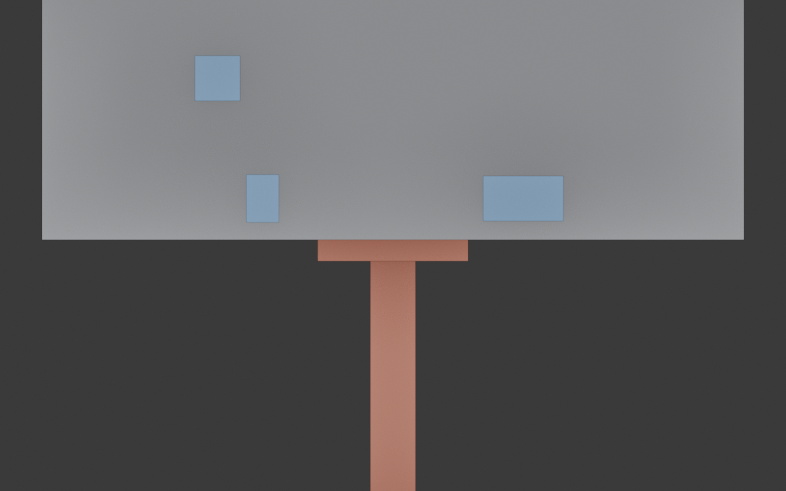
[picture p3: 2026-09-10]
cad/out/figures/front_from_bow.png

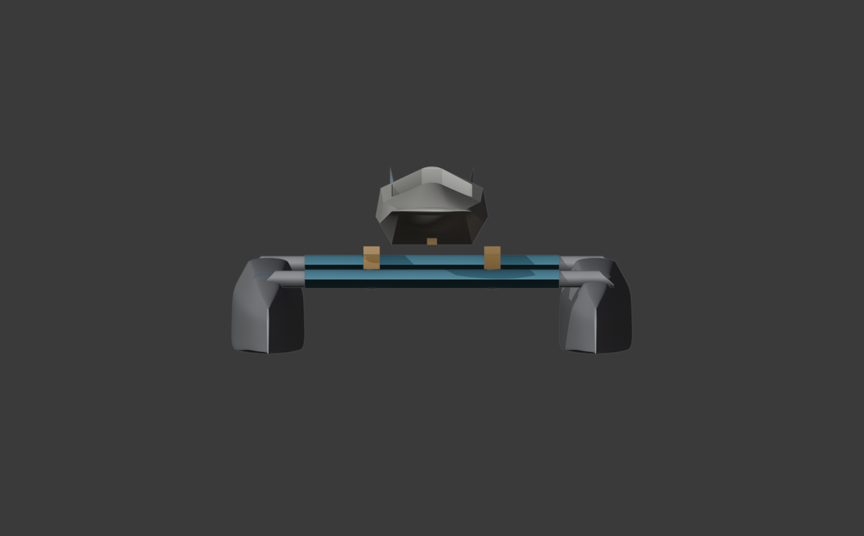
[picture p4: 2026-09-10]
cad/out/figures/volare_front.png

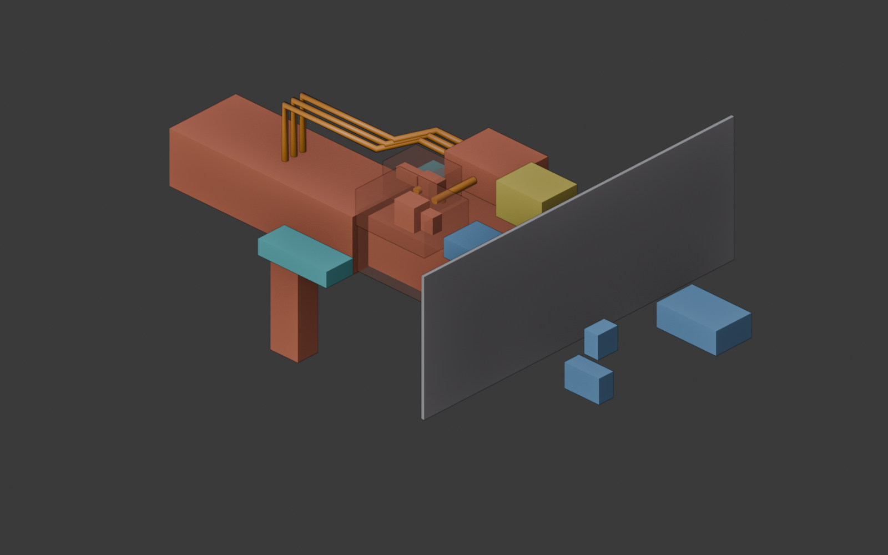
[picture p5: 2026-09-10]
cad/out/figures/iso.png

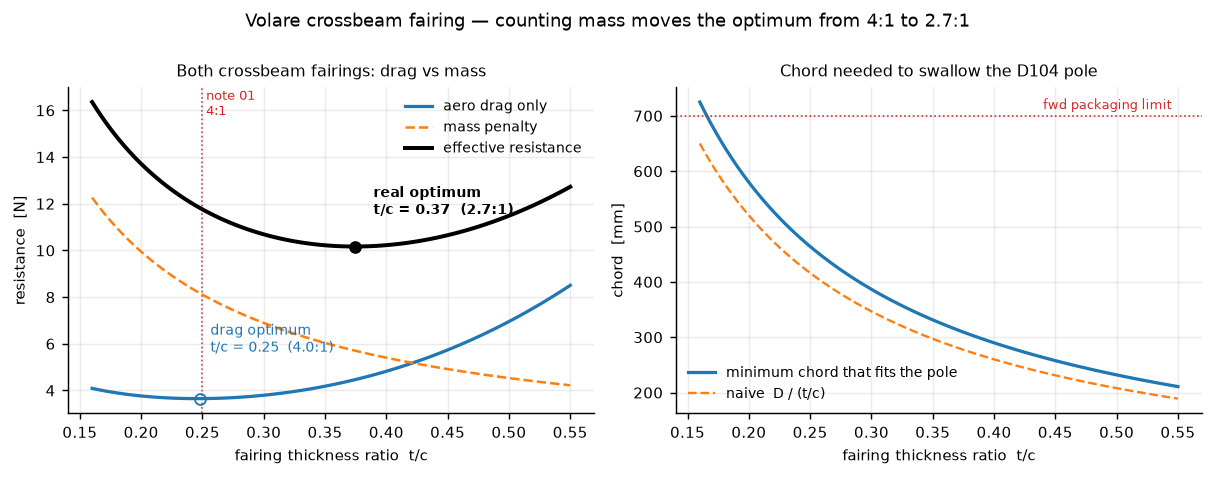
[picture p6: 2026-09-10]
cad/out/figures/fairing_trade.png

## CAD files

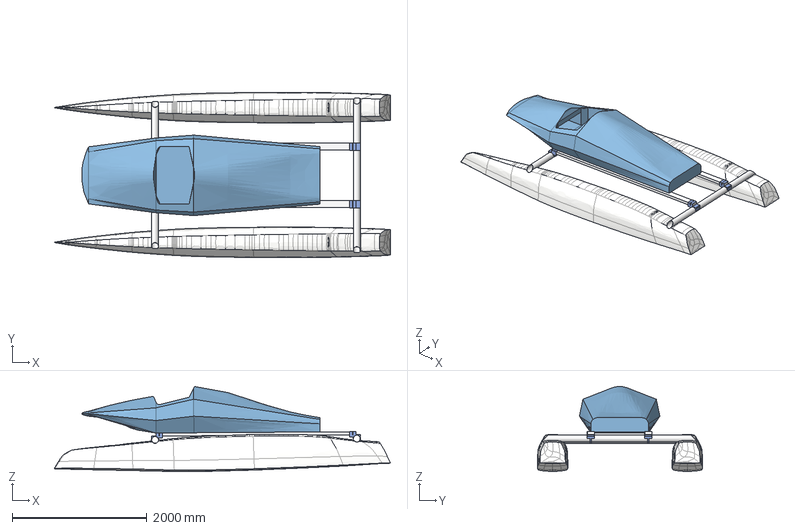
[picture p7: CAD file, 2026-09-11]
cad/blender/Main_Assembly_v_scaled.step
4995.3 x 2456.8 x 1264.6 mm
AFTERWARD BEAM__AFTERWARD BEAM
FORWARD BEAM__FORWARD BEAM

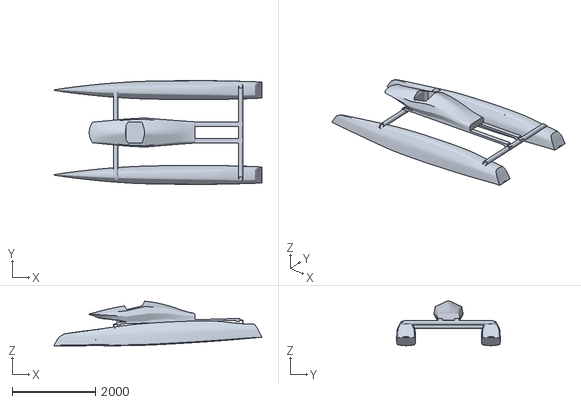
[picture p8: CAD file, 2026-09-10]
source_documents/FULLCOCPITV1_3.stl
4992.0 x 2489.0 x 1075.1

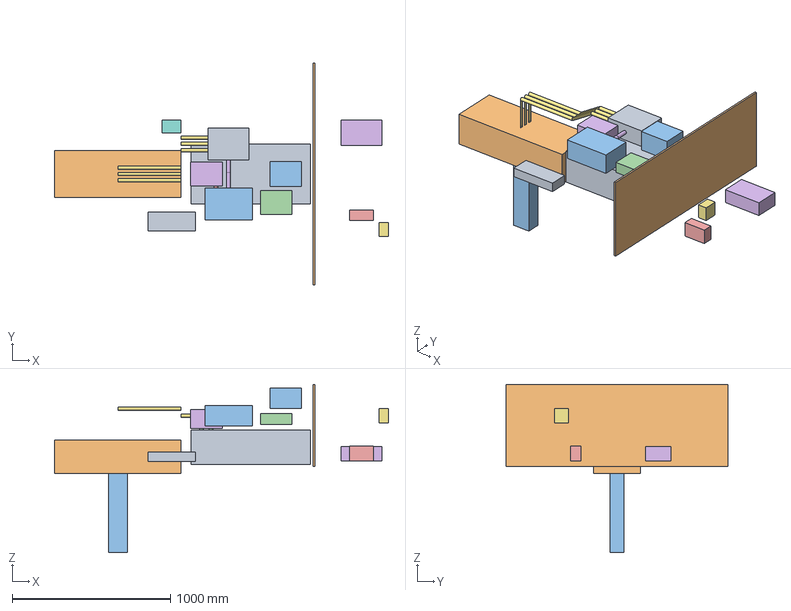
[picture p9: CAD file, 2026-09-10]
cad/out/volare_powertrain.step
2110.0 x 1400.0 x 1062.7 mm
energy_container
battery_pack
pdu
main_contactor
precharge_contactor
terminal_box
main_fuse
current_shunt
inverter
outboard
drive_leg
dcdc
lv_battery
vcu
estop
coolant_pump
heat_exchanger
bulkhead
monitor_bay
hv_pack_pos
hv_pack_neg
hv_fused_pos
hv_fused_neg
hv_pdu_to_inverter
phase_U
phase_V
phase_W

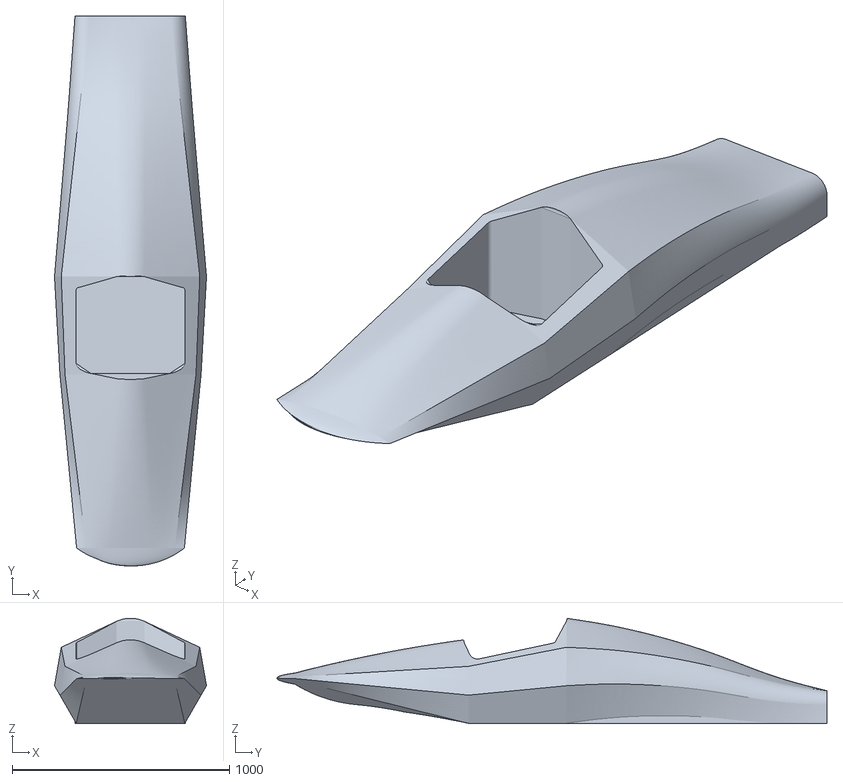
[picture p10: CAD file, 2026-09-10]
source_documents/Cockpit_V1_3.stl
700.0 x 2532.5 x 485.6

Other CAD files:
cad/out/volare_baseline.blend
cad/out/volare_frame_v2.blend
cad/out/volare_full_assembly.blend
cad/out/volare_parametric.blend
cad/out/volare_powertrain.FCStd
cad/out/volare_powertrain.blend

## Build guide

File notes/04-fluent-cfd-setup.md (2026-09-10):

---
tags: [volare, cfd, fluent, meshing]
---

# 04 — Fluent CFD Setup

Parent: [[00 - Master Brief]] · Objectives defined in [[01 - Aerodynamic Redesign]] §2

Hardware: RTX 5080 (16 GB, 84 SM) + RTX 4050 (6 GB, 20 SM).

## 1. Licence and GPU reality check

The Fluent native GPU solver has been available since 2023 R1 and requires a CFD Enterprise licence (2023 R1+) or CFD HPC Ultimate (2025 R1 SP2+). Licensing is by **streaming multiprocessor count, with 40 SMs included in CFD Enterprise**; beyond that you need HPC add-ons.

Consequences for you:
- Your **RTX 5080 has 84 SMs** — more than the 40 included. Check with your Ansys contact whether you can use all of them or will be capped at 40. Either way it runs.
- **Do not run the two cards together.** Mixed-GPU jobs are limited by the slowest card and the smallest VRAM, and load imbalance kills the speedup. Solve on the 5080, use the 4050 for pre/post.
- **VRAM budget: ~1.2–3 GB per million cells** depending on physics. On 16 GB single-precision steady SIMPLE, plan for **8–12 M cells**. That is enough for this model if you use the symmetry plane.
- Verify your Fluent release supports Blackwell (sm_120) — 2025 R1 or later is the safe assumption. Confirm before you build a 12 M cell mesh you cannot solve.

Fall back to the CPU pressure-based coupled solver if the licence blocks GPU; the meshes below are still tractable, just slower.

## 2. Domain

Boat is symmetric about the centreline (Y = −948.5 mm) → **model half the boat.** This halves the cell count and is the difference between fitting in 16 GB and not.

With L = 5.0 m (hull length):

| Boundary | Distance | Type |
|---|---|---|
| Inlet | 3L = 15 m upstream | velocity-inlet, 15.278 m/s, I = 0.5%, ℓ = 0.1 m |
| Outlet | 7L = 35 m downstream | pressure-outlet, 0 Pa gauge |
| Side (outboard) | 4L = 20 m | symmetry |
| Top | 4L = 20 m | symmetry |
| Centreline | Y = −948.5 mm | symmetry |
| **Water surface** | at design waterline Z | **symmetry** |

**On the water surface:** for the aero study, treat the free surface as a flat **symmetry** plane at the design waterline. Zero shear is correct here — in the boat's reference frame the water moves *with* the boat, so there is no relative velocity and no boundary layer. Using a no-slip wall would fabricate a boundary layer that does not exist and overpredict the beam drag (the beams sit only ~190 mm above the static waterline, so they are inside that fictional layer).

Set the waterline from your hydrostatics: at 320 kg all-up, 0.156 m³ per demihull vs 0.593 m³ moulded → ~27% immersion → static waterline ≈ **Z = −667 mm**. Run a second case at the planing attitude (bow-up 3°, waterline 100 mm lower) as a sensitivity.

## 3. Boundary layer resolution

$$Re_{pod} = 2.59\times10^6,\quad C_f = \frac{0.026}{Re^{1/7}} = 0.00315,\quad \tau_w = 0.451\ \text{Pa},\quad u_\tau = 0.607\ \text{m/s}$$

| Target | First layer height |
|---|---|
| **y⁺ = 1** | **0.0247 mm** |
| y⁺ = 30 (wall functions) | 0.742 mm |

Boundary layer thickness δ = 0.37L/Re^0.2 = **49 mm**.

| Growth rate | Layers to cover δ |
|---|---|
| 1.15 | 41 |
| **1.20** | **33** |
| 1.25 | 28 |

**Strategy — hybrid, to fit the memory budget:**
- **y⁺ < 1, 30 prism layers at 1.2 growth** on: pod shell, windscreen, beam fairings, rail nose cones. These are where you need separation prediction, and SST is only trustworthy with a resolved wall.
- **y⁺ 30–100, 12 layers** on: hull above waterline, brackets, everything else.
- Fluent's SST uses automatic wall treatment so the blend is legal — but never leave a surface in the 3 < y⁺ < 15 buffer-layer range, which is the one place both treatments are wrong. Check with a y⁺ contour plot on every wall zone before you trust a result.

## 4. Mesh

Fluent Meshing **watertight geometry workflow**, poly-hexcore:

| Region | Surface size |
|---|---|
| Beam fairing leading edge | 2 mm |
| Windscreen edges, coaming | 3 mm |
| Pod shell general | 6 mm |
| Rails, brackets | 5 mm |
| Hull above waterline | 15 mm |
| Far field | 400 mm growth-limited |

Bodies of influence:
- BOI-1: box enclosing pod + both beams + 0.5 m clearance, 20 mm max cell
- BOI-2: wake box from transom to 3 m aft, 60 mm max cell — you need this resolved or the total-pressure-deficit metric is meaningless
- BOI-3: 150 mm-radius cylinder along each beam fairing wake

Expected: **7–10 M cells** half-model. Curvature normal angle 12°, min size 1.5 mm, cells per gap 4.

Quality gates before solving: max skewness < 0.85, min orthogonal quality > 0.15, max aspect ratio < 500 in the prism layers.

## 5. Solver settings

```
Solver:        pressure-based, steady, single precision (GPU)
Scheme:        Coupled, pseudo-transient, length scale = 2.5 m
Turbulence:    k-omega SST, curvature correction ON,
               production limiter ON
Wall roughness: smooth baseline;
               sensitivity case at Ks = 75e-6 m, Cs = 0.5
Discretisation: pressure       -> Second Order
                momentum       -> Second Order Upwind
                k, omega       -> Second Order Upwind
                gradient       -> Least Squares Cell Based
Initialisation: Hybrid, then 200 first-order iterations,
                then switch to second order
Convergence:    residuals < 1e-5 AND
                C_D on pod-shell stable to <0.5% over 500 iters
Reporting:      average forces over final 500 iterations
```

**Turbulence model note:** run k-ω SST as baseline. Do *not* use k-ε for this — it systematically underpredicts separation on the aft body, which is precisely the thing you are trying to detect. If the aft body shows marginal separation, re-run with GEKO (C_SEP tuned to 1.0) as a cross-check. Ignore transition models: hand-laid gelcoat at Re 2.6 × 10⁶ is fully turbulent from the nose.

**If the residuals stall or C_D oscillates**, that is physical, not numerical — the bare square beams shed vortices. Either accept the oscillation and time-average, or switch that case to URANS (Δt = 0.002 s, 20 inner iterations). Once faired, the oscillation disappears, which is itself a useful result to show the jury.

## 6. Run matrix

| # | Case | Purpose |
|---|---|---|
| 1 | Baseline geometry, 15.28 m/s | Validate the 2.58 kW estimate in [[00 - Master Brief]] §2 |
| 2 | Beam fairings only | Isolate the 2.0 kW claim |
| 3 | Fairings + windscreen + shoulder fairing | Isolate the pilot term |
| 4 | Full optimised pod (recontoured aft body) | Final |
| 5 | Case 4 at 8.3 m/s (30 km/h) | Endurance-speed check |
| 6 | Case 4 at ±3° pitch | C_L and trim moment sensitivity |
| 7 | Case 4 with 6 m/s crosswind at 20° yaw | Heeling moment, Monaco harbour |
| 8 | Case 4, Ks = 75 µm | Surface finish sensitivity |

Cases 6 and 7 matter more than they look. Yaw is the realistic operating condition and a low-AR pod develops a large side force and yawing moment that the symmetric head-on case never shows.

## 7. Verification you must do before quoting numbers

1. **Mesh independence.** Three meshes at r = 1.5 refinement ratio (≈3 M, 7 M, 15 M cells if the 15 M fits; otherwise 2/4.5/10 M). Compute the Grid Convergence Index per Roache:
   $$GCI = \frac{F_s|\varepsilon|}{r^p-1},\quad F_s = 1.25$$
   Report C_D with its GCI band. A number without this is not a result.
2. **Benchmark case.** Mesh and solve an isolated square cylinder in crossflow at Re = 1.4 × 10⁵ with your exact settings. Literature C_D = 2.05–2.1. If you do not land inside that band, your beam drag numbers are wrong and everything downstream is too.
3. **Domain independence.** Rerun case 1 with the side and top boundaries at 6L. Blockage ratio should be < 1%; if C_D moves > 1%, the domain is too small.

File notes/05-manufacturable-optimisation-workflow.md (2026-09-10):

---
tags: [volare, optimisation, fea, composites]
---

# 05 — Manufacturable Optimisation Workflow

Parent: [[00 - Master Brief]] · Structure defined in [[03 - Composite Structure]]

## 1. Why classical topology optimisation is the wrong tool here

You asked for topological optimisation. Density-based (SIMP) topology optimisation solves:

$$\min_{\rho} \ c(\rho)=\mathbf{u}^T\mathbf{K}(\rho)\mathbf{u} \quad \text{s.t.} \quad \frac{V(\rho)}{V_0}\le f,\quad E_e = E_0\rho_e^p$$

and returns a continuous 3D density field, which post-processing turns into an organic, variable-thickness solid. That output is manufacturable by casting, machining or metal AM. It is **not manufacturable by hand layup on a female mould**, where the only design variables you actually control are:

1. Number of plies at each location (integer, and each ply must be a contiguous piece of fabric)
2. Fibre orientation of each ply (in practice 0/90 or ±45 for woven roving)
3. Core thickness (discrete — 10, 15, 20, 25 mm stock)
4. Where local doublers and inserts go

Feeding SIMP output to a wet-layup shop produces a shape they will quote, decline, or approximate badly. **Use the formulation whose design variables match the process.**

## 2. The correct three-stage route

### Stage 1 — Topology optimisation used as a *diagnostic*, not a geometry generator

Still run it, but read it as a load-path map.

- Model: shell FE of the pod, uniform 20 mm sandwich, Ansys Mechanical
- Load cases: LC-1 pilot 3g, LC-2 self-mass 3g, LC-O rollover 2354 N at the crown, LC-R racking via prescribed rail displacement
- Objective: minimise compliance, 40% mass fraction
- **Read the result as: where do stiffeners and doublers belong?** The high-density ribbons are your reinforcement paths.

Manufacturing constraints to apply so the answer is at least interpretable: symmetry about the centreline, minimum member size 60 mm, and a pull-direction (extrusion) constraint aligned with the mould axis.

### Stage 2 — Convert load paths into a zoned, discrete build

Translate the ribbons into a physical layup you can actually specify:

| Optimiser output | Wet-layup realisation |
|---|---|
| High-density ribbon | Extra 600 gsm WR doubler, 150 mm wide, along the ribbon |
| Dense node | Solid insert, core removed, 3:1 chamfer |
| Dense region under seat | Core step 15 → 20 mm |
| Low-density region | Drop to 10 mm core, minimum skin |

Ply-drop rules from [[03 - Composite Structure]] §8 apply to every one of these transitions — 20:1 taper, staggered ≥ 25 mm, ≤ 2 plies at a time.

### Stage 3 — Parametric sizing optimisation (this is where the mass actually comes out)

This is the stage that replaces SIMP and is fully manufacturable. Set up in Ansys ACP + Mechanical, driven by DesignXplorer.

**Design variables (all discrete, all buildable):**

| Variable | Range | Step |
|---|---|---|
| n_WR outer skin, zone 1–4 | 1–3 plies | 1 |
| n_WR inner skin, zone 1–4 | 1–2 plies | 1 |
| Core thickness, zone 1–4 | 10 / 15 / 20 / 25 mm | discrete |
| Doubler width, 3 paths | 100–250 mm | 25 mm |
| Rail insert pitch | 150–400 mm | 50 mm |

**Objective:** minimise shell mass.

**Constraints:**

| Constraint | Limit | Source |
|---|---|---|
| Floor deflection under LC-1 | ≤ 2.0 mm (L/200) | [[03 - Composite Structure]] §3 |
| Skin strain, any ply, any LC | ≤ 3000 µε | wet-layup fatigue allowable |
| Core shear stress | ≤ 0.38 MPa (H60, FoS 2) | H60 τ_ult 0.76 MPa |
| Skin wrinkling | no wrinkling at 1.5× LC | §3 below |
| Roll crown deflection under LC-O | ≤ 25 mm | helmet clearance |
| Global torsional stiffness | ≥ baseline | LC-R |

Use Response Surface Optimisation with a Central Composite design — the variable count is small enough that you get a good surrogate in ~60 solves, each a few minutes on the 4050. Then verify the optimum with a direct solve.

**Realistic outcome:** 15–20% off the uniform-schedule 28.9 kg, i.e. **24–25 kg** for the shell.

## 3. Failure modes the optimiser will exploit if you do not constrain them

Sandwich optimisers reliably converge to thin skins over thick core, which fails in modes a shell FE will not report unless you add them explicitly:

**Skin wrinkling** (local skin instability on the core):
$$\sigma_{wr} = 0.5\left(E_f E_c G_c\right)^{1/3}$$
For E_f = 10 GPa, H60 (E_c = 60 MPa, G_c = 20 MPa): σ_wr = 0.5 × (10⁹ × 6 × 10⁷ × 2 × 10⁷)^(1/3) ≈ **53 MPa**. Your working skin stress is 8 MPa, so FoS ≈ 6.6 — safe at the current schedule, but it drops as the optimiser thins the skins. **Add it as an explicit constraint** or you will get a 1-ply skin that wrinkles.

**Intracell dimpling** — only relevant if you switch to honeycomb. Not an issue with foam or cork.

**Core crushing at inserts** — H60 compressive strength 0.9 MPa. Any bolt not going through a solid insert will crush the core over a season of slamming. This is the single most common failure in student-built composite hulls.

## 4. Sequencing

Do these in order — later stages depend on earlier ones and you cannot parallelise them:

1. Weigh the hulls. Get bulkhead stations. Read the rule text. *(blocks everything)*
2. Fix the frame layout — crossbeam positions, rail span ([[02 - Support Frame Design]] §3.1). *This changes the pod's boundary conditions, so the FE model is not valid until it is frozen.*
3. Resolve the 83 mm rail interference and the opening size.
4. Run CFD case 1 to validate the drag budget. If the beams really are 77% of it, everyone on the team stops arguing about pod curvature.
5. Build fairings and recontour the aft body → CFD cases 2–8.
6. FE Stage 1 and 2 in parallel with the CFD.
7. Stage 3 sizing optimisation. Freeze the laminate.
8. Send the moulder the ply book and the radius/draft schedule.

Step 4 before step 5 matters: you want the baseline number measured, not assumed, because the whole priority ordering in [[00 - Master Brief]] rests on it.

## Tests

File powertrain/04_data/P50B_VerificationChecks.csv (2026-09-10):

Category | Name | Pass | Detail | Severity
Architecture | Total cell count | 1 | 26 series x 21 parallel = 546 cells | ERROR
Architecture | Cell table height | 1 | 546 rows in the cell table | ERROR
Architecture | Group table height | 1 | 26 rows in the group table | ERROR
Architecture | Cells per group | 1 | min 21, max 21 | ERROR
Architecture | Cells per layer | 1 | layer 1: 273, layer 2: 273 | ERROR
Architecture | Group array shape | 1 | 3 rows x 7 columns | ERROR
Geometry | Cell coordinates finite | 1 | All 546 cell positions are finite | ERROR
Geometry | Series path adjacency | 1 | longest step 174.9 mm | ERROR
Geometry | Grid capacity | 1 | 16 slots for 13 groups, 3 spare | ERROR
Geometry | Packaging efficiency | 1 | 32.8% of external volume is cell | WARNING
Electrical | Pack nominal voltage | 1 | 93.60 V | ERROR
Electrical | Pack maximum voltage | 1 | 109.20 V | ERROR
Electrical | Pack capacity | 1 | 105.0 Ah | ERROR
Drivetrain | Series count matches outboard | 1 | Pack is 26S, Competr datasheet specifies 26S | ERROR
Drivetrain | Maximum voltage within outboard limit | 1 | Pack max 109.2 V vs outboard limit 109 V | ERROR
Drivetrain | Minimum voltage above inverter floor | 1 | Pack min 65.0 V at the cell cut-off | WARNING
Drivetrain | Pack can supply outboard continuous current | 1 | Cells allow 1260 A, outboard draws up to 375 A | ERROR
Drivetrain | Cell current at outboard continuous rating | 1 | 17.86 A/cell (3.57 C), datasheet limit 60 A | ERROR
Drivetrain | Cell current at 42 kW peak | 1 | 21.37 A/cell at 449 A pack current | ERROR
Drivetrain | Energy vs Competr stock pack | 1 | This pack 9.83 kWh vs stock 26 kWh (38% of it) | INFO
Interconnect | Current density: Monaco cap, nominal V | 1 | links 3.0, rails 3.2 A/mm2 (continuous limit 5.0) | WARNING
Interconnect | Current density: Monaco cap, minimum V | 1 | links 4.3, rails 4.6 A/mm2 (continuous limit 5.0) | WARNING
Interconnect | Current density: Competr hardware continuous | 1 | links 4.2, rails 4.5 A/mm2 (continuous limit 5.0) | WARNING
Interconnect | Current density: FAULT: cap failure, 42 kW | 1 | links 7.2, rails 7.7 A/mm2 (peak limit 8.0) | WARNING
Interconnect | Voltage drop at continuous current | 1 | 0.58 V (0.62% of nominal) at 375 A | WARNING
Harness | Cable ampacity vs continuous current | 1 | 150 mm2 gives 459 A derated, need 375 A | ERROR
Harness | Fuse clears worst legal operating current | 1 | 400 A fuse vs 385 A worst legal draw (25 kW at the 65 V minimum bus) | ERROR
Harness | Fuse below protected conductor ratings | 1 | 400 A fuse, cable 459 A, busbar 450 A (Monaco ENERGY_REQ_59) | ERROR
Auxiliary | DC/DC headroom at simultaneous peak | 0 | Peak 12 V load 1118 W vs 1000 W converter | WARNING
Thermal | Steady temperature at Monaco power cap | 1 | 35.1 degC steady, design limit 45 degC | ERROR
Thermal | Steady temperature at outboard continuous | 1 | 44.9 degC steady at 375 A | WARNING
Inverter | Device rating requirement identified | 1 | Needs >= 418 A device rating for 42 kW peak | INFO
Inverter | Selection status | 0 | Inverter not yet selected -- Competr lists it as 'on request' | INFO

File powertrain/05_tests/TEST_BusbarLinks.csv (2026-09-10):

LinkID | FromGroup | ToGroup | LinkLength | LinkArea | LinkResistance | LinkPowerLoss | LinkSurface | IsInterLayer
1 | 1 | 2 | 0.2010775 | 9e-05 | 4.45724651435556e-05 | 3.17976462793144 | BOTTOM | 0
2 | 2 | 3 | 0.2010775 | 9e-05 | 4.45724651435556e-05 | 3.17976462793144 | TOP | 0
3 | 3 | 4 | 0.2010775 | 9e-05 | 4.45724651435556e-05 | 3.17976462793144 | BOTTOM | 0
4 | 4 | 5 | 0.0927475 | 9e-05 | 2.05591610742222e-05 | 1.46667439086457 | TOP | 0
5 | 5 | 6 | 0.2010775 | 9e-05 | 4.45724651435556e-05 | 3.17976462793144 | BOTTOM | 0
6 | 6 | 7 | 0.2010775 | 9e-05 | 4.45724651435556e-05 | 3.17976462793144 | TOP | 0
7 | 7 | 8 | 0.2010775 | 9e-05 | 4.45724651435556e-05 | 3.17976462793144 | BOTTOM | 0
8 | 8 | 9 | 0.0927475 | 9e-05 | 2.05591610742222e-05 | 1.46667439086457 | TOP | 0
9 | 9 | 10 | 0.2010775 | 9e-05 | 4.45724651435556e-05 | 3.17976462793144 | BOTTOM | 0
10 | 10 | 11 | 0.2010775 | 9e-05 | 4.45724651435556e-05 | 3.17976462793144 | TOP | 0
11 | 11 | 12 | 0.2010775 | 9e-05 | 4.45724651435556e-05 | 3.17976462793144 | BOTTOM | 0
12 | 12 | 13 | 0.0927475 | 9e-05 | 2.05591610742222e-05 | 1.46667439086457 | TOP | 0
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

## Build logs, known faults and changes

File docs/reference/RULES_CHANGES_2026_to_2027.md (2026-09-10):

# Rules changes, Monaco Energy Class 2026 → 2027

Source documents, both in `docs/reference/`:

- `Technical_Rules_Energy_Class_2027_V1.pdf`, version 2027.1, issued 07/09/2026
- `MEBC_Notice_of_Challenge_2027_V1.pdf`, version 1.0, issued 04/09/2026

The 2026 documents are kept in `archive-2026/` rather than deleted, because
design decisions already recorded in `notes/` were made against them.

Method: every `ENERGY_REQ_n vX.Y` token was extracted from both documents and
compared by identifier and version, then each difference was read in full.
Both years contain 174 requirements. **Four are new, four were withdrawn, and
eleven were revised.**

---

## 1. The change that matters most

### ENERGY_REQ_188 v1.0 → v1.1 — the 25 kW power cap tightened

| | Text |
|---|---|
| **2026** | The total **nominal** power consumption of the motor(s) shall not exceed 25 kW. |
| **2027** | The sum of **instantaneous** power consumption of all motors shall not exceed 25 kW. *Note: No power exceeding 25 kW will be allowed, even during a peak.* |

This is a real tightening, not a rewording. "Nominal" left room to argue that a
short peak above 25 kW was permitted. "Instantaneous", with an explicit note
about peaks, closes that. It also now applies to the **sum over all motors**,
which matters for any multi-motor architecture.

**Effect on this project: none, and that is the point.** `propulsor/config.m`
already enforces `P_cap_W = 25e3` for every duration. What changes is the
justification: this is a competition rule, not a team preference, so it is not
negotiable and the optimiser must never be allowed to breach it.

---

## 2. New requirements

### ENERGY_REQ_194 v1.0 — motor seat structural load

> The motor seat structure shall withstand a torque load equivalent to at least
> 200% of the maximum torque generated by the motor at full power.
> *Note: The design should integrate peak power to full power.*

**Directly affects the propulsor and the frame.** With a 100 N·m maximum motor
torque, the motor seat must be designed to **200 N·m**. This is a new structural
case for `structures/` and for `propulsor/structural_model.m` when it is
written. Nothing in the repository currently checks it.

### ENERGY_REQ_195 v1.0 — power sensor mounting volume

> The team shall provide a free mounting volume of 220 × 111 × 80 mm (L × W × H)
> for each power sensor device provided by the Organiser [...] This area shall
> be water proof [...] one sensor per traction chain.

**Affects the cockpit layout.** A waterproof 220 × 111 × 80 mm volume per
traction chain. A single motor means one volume. `cad/scripts/layout.py` and
`pack_fit.py` do not currently reserve it.

### ENERGY_REQ_193 v1.0 — battery chemistry, from August 2028

> From August 2028, lithium-ion batteries shall use LFP chemistry. Solid-state
> batteries are also permitted. Any other battery technology shall require prior
> approval from the Technical Committee.

**Not binding for the 2027 event, but decisive for the pack after it.** The
Molicel INR21700-P50B is an NMC cell; "INR" denotes nickel-manganese-cobalt.
The entire `powertrain/` model is built around it. It is compliant for 2027 and
would not be compliant from August 2028 without Technical Committee approval.

Worth raising now rather than after the pack is built.

### ENERGY_REQ_192 v1.0 — hull protection

> When off the water, the hulls shall be adequately protected.

Operational. No design effect.

---

## 3. Withdrawn requirements

All four were in the 2026 rules and are absent from 2027.

| Requirement | 2026 text | Status |
|---|---|---|
| ENERGY_REQ_153 | Transponder for tracking may be provided by the Organisation and shall be positioned on each boat | Withdrawn; not referenced in this repository |
| ENERGY_REQ_174 | Bulkhead hole diameter shall be no less than 30 mm | **Withdrawn; checked by our compliance code** |
| ENERGY_REQ_175 | Bulkhead hole shall not exceed 50 mm and shall be covered with a removable cap | **Withdrawn; checked by our compliance code** |
| ENERGY_REQ_176 | The hole shall not be oriented directly to the pilot, but on his side | **Withdrawn; checked by our compliance code** |

The bulkhead hole specification was removed entirely, with no replacement.
`ENERGY_REQ_55`, requiring grommets on wire holes through the bulkhead,
survives unchanged.

`powertrain/08_compliance/P50B_MonacoCompliance.m` checks 174 and 175 and
mentions 176. Those checks are now marked **WITHDRAWN 2027** rather than
deleted, so the audit trail of what was once required survives.

---

## 4. Revised requirements

### Affecting design

**ENERGY_REQ_186 v1.0 → v1.1 — hydrofoils banned**

| | Text |
|---|---|
| 2026 | No cockpit appendices shall be in contact with the water, except for the motor and the water pump. |
| 2027 | **Hydrofoils are not permitted.** No cockpit appendices shall be in contact with the water, except for the motor and the water pump. |

The prohibition is now explicit. Note this does **not** affect
`propulsor/hydrofoil_polar.m`, which concerns the aerofoil sections of the
propeller blade, not lifting foils on the hull. The naming collision is
unfortunate; the file is correctly named for what it does.

**ENERGY_REQ_184 v2.0 → v1.1 — monitoring power interface**

Maximum power raised from **30 W to 35 W**, and the connector part numbers
changed from `BD-02BFFA-LL7001` / `ABD-02AFFM-LL7A03` to `AD-02BFFA-LL7001`,
`1AD-02BFFM-LL7AXX` or `AAD-02BFFM-LL7AXX`, all Amphenol LTW. **Check what has
been ordered.**

**ENERGY_REQ_185 v2.0 → v1.1 — external monitoring volume**

Volume unchanged at 190 × 150 × 122 mm and still open to the sky, but 2027 adds
that it must be **at least 40 cm above the beams of the hulls** and outside all
closed compartments. That is a new placement constraint on the cockpit.

**ENERGY_REQ_93 v1.0 → v1.1 — surface temperature**

"Exposed parts shall not reach more than 60 °C" became "**Any reachable
surface** shall not exceed a temperature of 60 °C". Broader: a surface a hand
can reach now counts even if it is not exposed. Relevant to
`powertrain/07_simulation/P50B_ThermalDesign.m`.

### Clarifications with no numerical effect

| Requirement | Change |
|---|---|
| ENERGY_REQ_7 v1.2 → v1.3 | 10 kWh cap and every energy factor unchanged. Typographical only: "define" → "defined". |
| ENERGY_REQ_48 v3.0 → v3.1 | **250 kg limit unchanged.** Notes renumbered; hull mass still 65 ±1 kg. |
| ENERGY_REQ_2 v1.1 → v1.2 | Hull build spec unchanged. New Note 2 permits Organiser-approved alterations that give no competitive advantage, with weight adjustment. |
| ENERGY_REQ_155 v1.1 → v1.2 | New note: nested battery containers each need an overpressure valve. |
| ENERGY_REQ_181 v1.0 → v1.2 | ESC input power diagram, now cross-referenced from the new ENERGY_REQ_195. |
| ENERGY_REQ_56 v2.0 → v2.1 | Fire extinguisher port. Text identical. |

---

## 5. Unchanged, and load-bearing for this project

Confirmed identical in both years. Every number the code depends on survives.

| Requirement | Value |
|---|---|
| ENERGY_REQ_48 | Overall weight excluding hulls **≤ 250 kg**, hulls 65 ±1 kg |
| ENERGY_REQ_7 | Stored energy **< 10 kWh**, battery factor 1.0, hydrogen 0.35, flywheel 0.5, heat 0.3 |
| ENERGY_REQ_3 | Teams shall not modify the hulls and beams provided |
| ENERGY_REQ_28 | Solar panels **≤ 4 m²** including mounting frame |
| ENERGY_REQ_37 | Boat shall sail at **at least 3 knots** |
| ENERGY_REQ_154 | Steering shall rotate **at least 40°** each side |
| ENERGY_REQ_32 | Forward and reverse required |

---

## 6. Event dates, 2027

From the Notice of Challenge. Racing is **Thursday 1 July to Saturday 3 July
2027**, paddocks cleared Sunday 4 July at noon. Technical inspection and
registration close the preceding Wednesday. Boats must be presented no later
than **Tuesday 26 June 2027, 09:00**.

Withdrawal after **1 May 2027** forfeits the registration fee unless another
team takes the place.

---

## 7. Actions arising

1. **Reserve 220 × 111 × 80 mm, waterproof, for the Organiser power sensor**
   (ENERGY_REQ_195). Not currently in the layout.
2. **Design the motor seat to 200 N·m**, twice the 100 N·m motor maximum
   (ENERGY_REQ_194). No current check.
3. **Check the ordered monitoring connector part number** against the revised
   ENERGY_REQ_184 list, and the interface budget against 35 W.
4. **Move the external monitoring volume at least 40 cm above the hull beams**
   (ENERGY_REQ_185).
5. **Decide the post-2028 cell.** The P50B is NMC and ENERGY_REQ_193 requires
   LFP or solid-state from August 2028. Fine for 2027, not beyond it.
6. Confirm no part of the design relies on lifting hydrofoils (ENERGY_REQ_186).

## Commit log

2026-09-10 Restructure repository into the layout both codebases expect
    The repository was a flat dump of 202 files at the root. That broke path
    resolution in both projects, silently rather than loudly.
    Structure was recovered from the code, not invented:
    - TEST_ALL.m carries a 23-entry manifest naming 00_common through
    08_compliance; other MATLAB files reference 04_data, 05_tests, 09_hydro,
    params, output and tools.
    - cad/scripts modules resolve the repo root as Path(__file__).parents[2]
    and expect cad/out, cad/out/figures and source_documents beneath it.
    - CLAUDE.md and the Blender scripts' docstrings specify cad/scripts,
    cad/blender and notes.
    Both projects now work with zero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
    [Cockpit_V1_3.stl, FULLCOCPITV1_3.stl, P50B_BusbarLinks.csv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]
2026-09-10 Plan the propulsor rebuild and adopt Octave as the CI runtime
    Assessed whether to delete propulsor/ and restart. Salvage, not restart.
    Reading the code rather than its README: bem_rotor.m reduces the coupled
    (a, a') system to one scalar equation per radial station and solves it with
    Illinois bracketing, on a cell-centred grid, having explicitly rejected
    fixed-point iteration as unstable at high solidity. It also shows the
    immersion duty factor cancels in the induction but not in the loads, which is
    the correct statement of the surface-piercing disk-area penalty.
    optimization_driver.m already carries toolbox-free pso_local and
    pattern_search; objective_function.m already carries the manufact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
2026-09-10 Propulsor stages 0-2: units, resistance and the 25 kW motor envelope
    Team decision applied: the motor is capped at 25 kW at all times, peak equal
    to continuous. No operating point of any duration may exceed it.
    params.motor.P_cap_W is the enforced ceiling. The supplied 42 kW datasheet
    peak stays recorded in P_max_spec_W with usePeakSpec = false, so nothing
    supplied is silently altered and the contradiction stays visible for the
    supplier conversation. motor_consistency_report.m prints it with the numbers
    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
2026-09-10 Adopt the 2027 rules; the 25 kW cap is ENERGY_REQ_188, not a preference
    Replaced the 2026 Technical Rules and Notice of Challenge with the 2027
    editions (2027.1, issued 07/09/2026). The 2026 documents move to
    docs/reference/archive-2026/ rather than being deleted, because decisions
    already recorded in notes/ were made against them.
    Compared both documents requirement by requirement: 174 in each year, with
    4 new, 4 withdrawn and 11 revised. Full record in
    docs/reference/RULES_CHANGES_2026_to_2027.md.
    The consequential change is ENERGY_REQ_188 v1.0 -> v1.1. The 2026 wording
    capped "total NOMINAL power consumption of the motor(s)", which left room to
    argue a brief peak was permissible. The 20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
2026-09-11 Propulsor stages 3 and 4: the BEM solver runs end to end
    Built hydrofoil_polar.m, propeller_geometry.m, prandtl_loss.m,
    bem_front_rotor.m and bem_rear_rotor.m. The blade element momentum solver now
    converges at every advance ratio tested.
    Interface catch: bem_rotor.m calls
    hydrofoil_polar(alpha, Re, toc, foc, vent, params) returning two plain arrays,
    not the struct-returning signature written first. Rewritten to match the
    existing caller. That also added the ventilated-section branch the config
    already parameterises: linearised supercavitating theory gives a lift slope of
    pi/2 per radian against the wetted 2*pi, and the gate confirms the ratio at
    4.25 once the thickness correction is includ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
2026-09-11 Fix the failing powertrain design checks; three were modelling bugs
    powertrain.py reported 3 of 15 checks failing. Two were bugs in the checks
    themselves, one was a real physical error in the design, and the genuine
    engineering problem was hidden behind them.
    1. STALE GEOMETRY EXPORT was a false alarm. The check compared file
    modification times, so annotating a comment in volare_params.json, which
    changes nothing the export depends on, made the file newer and reported the
    export stale. It was also silent in the opposite direction: touching the
    export file would make a genuinely stale export look current.
    It now compares the 12 VALUES the export was built from against the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
2026-09-11 Drive the CAD from the parameter file so design work can run in parallel
    Only 3 of the 24 scripts under cad/ read volare_params.json. The other 21
    hardcoded their numbers, so editing a parameter silently failed to reach the
    geometry. That is the thing this fixes: a parameter change now propagates into
    the CAD without anybody editing code.
    NEW: cad/scripts/params.py
    One loader, standard library only, so it runs unchanged under CPython,
    Blender's bundled Python and FreeCAD's. Blender ships without scipy and
    FreeCAD's interpreter is its own, so a loader needing either would be useless
    in exactly the places geometry is built. It resolves the file from its own
    location rather than the working d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
2026-09-11 Update the handoff for the structure and design session
    Records the three design-check fixes, the per-line mass audit, and the
    parameter-driven CAD chain. Next actions reordered: closing the 9.2 kg mass
    overrun is now first, and rerunning the MATLAB budget at the 70 kg pilot is
    second because it alone may close most of the gap.
    Claude-Session: https://claude.ai/code/session_01FXwEH6EYQbWHYwznb6zmjd
2026-09-11 Run the Blender builders; fix a numpy 2.x-only call that broke under Blender
    Installed Blender 4.0.2 headless and ran all five scene builders, which had
    never been executed in this repository. Four worked. One did not, and the
    failure is exactly the kind CLAUDE.md warns about.
    parametric_scene.py died on np.trapezoid. numpy renamed trapz to trapezoid in
    2.0: Blender 4.0 ships numpy 1.26, which has only the old name, while the
    analysis venv has 2.4. CLAUDE.md requires cad/scripts to run under Blender, so
    geom.py and parametric.py now bind the available name once and use that. Both
    verified under numpy 2.4 in the venv and 1.26 under Blender.
    Results from the runs:
    build_scene.py 17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
